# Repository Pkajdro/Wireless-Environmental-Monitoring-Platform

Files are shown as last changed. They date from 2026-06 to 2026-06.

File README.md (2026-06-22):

# Wireless Environmental Monitoring Platform

rn_image_picker_lib_temp_3451f50a-21aa-435d-9f39-d2db277a8afb

<br>

A remotely operated mobile robotics platform engineered for atmospheric data acquisition and exploration. The system enables remote clontrol of the driving platform and acquisition of humidity, pressure and temperature of air. Key feature is modularity - most parts can be changed without changing others and the whole robot, allowing for diffrent configurations.

This robot was made in collaboration with @Pita5488, who programed and installed the sensors, made the final versions of the code and of the KiCad scheme, etc.

<br>

# Key features
 - wireless control
 - modularity
 - built for uneven urban terrain
 - records temperature, pressure and humidity of the air

<br>
<br>

# Architecture
### Software and digital tool and languages:
 - Arduino IDE
 - KiCad
 - C/C++
 - Python
 - VScode
 - Tinkercad

### Hardware
 - Arduino Rev 4 Wifi/BT
 - L298N engine driver
 - 18650 batteries
 - WS2812 led stripe
 - DHT11 temperature and humidity sensor
 - HC-SR04 UV distance sensor
 - BMP280 digital barometer
 - yellow 3-6V DC Motors
 - other electronic

### Construction
- wooden main corpus
- wooden electronics board
- 3D-printed wheel guides

<br>
<br>

# In depth look
### Robots pourpose
Robot's main function is to record meterological data, while being remotely controled. 
The wireless control system allows the user to reach terrains humans can't or should't because of possible danger, like vents, contruction zones, post accidents zones like labs, radioactive terrain, etc.

### About software
We used the Arduino IDE, as it suited our need. We programmed the sensors, engines, etc., in many .h files to make the project clearer.

We decided that the robot should be controlled via laptop, so we created a Python app, allowing us to do so.

### About hardware
Our hardware was mostly mounted on the electronics board on the top of the robot.

### About construction
The whole idea of the robot was 1) to be large, so that it can be used in ubran enviroment, 2) to be modular, so that we can use it for many things.

Robots size is aprox. 50 cm in lenght, 25 in width and 30 in height. We decided to use wood for large parts of the robot, since PETG would be less sturdy, and wouldn't allow us to easily use bolts to mount it.

The main corpus is entirely made out of wpieces of wood bolted togather - the top part of the main corpus and sides used to bolt guides in.

Guides are made out of PETG using a 3D-printer. They have a 45° curve, to further strenghten its abilities to manuver in unever terrain

At the very top sits the electronics board, on which we mounded electronics like Arduino, engine drives, batteries and the breadboard with sensors.

### Modularity: The key aspect of Robot's construction
From the very beggining we decided to have a modelar build of the robot.

What does it mean?

It means that you can change almost every part easily and without changing any other parts.
We used M3 bolts with nuts on guides and the electronics board with, aloowing use to swapp them simply by unscrewing a few bolts.

Each engine guide (or "leg") can be individualy changed, allowing for diffrent configurations - feature which I already use (more about this is "What's next?" senction further down).
The detachable electronics board has also already come in handy - when I needed to code or tinker around it, i just detached it and didn't have to bring the whole robot with me.
It also allows the robot to have multiple pourposes, since all it takes to completly change the electronics is to swap in the new boards, connect engines to the driver, and you are good to go.

<br>
<br>

# What's still to fix?
The main problem with the robot is it size and weight - it causes the rotation of the to be very slow and unreliable.

During our testing we understood that because of robot's size, weight and teh fact that it's a skid-steer robot, it will not rotate well in this configuration.

Which takes us to...

<br>
<br>

# What's next?
--> The 2.0 version

What I aim to acomplish now is to piece by piece change the robot, so that the movement problem will be fixed.
My engineering thesis patreon sugested to use passive wheels on the back, so that you only need to motors to control the robot.
This idea was already implemented by me - unsuprisingly it did 2 things: fix the movement issue and create new problems.
The problem was that 2 engines at which power supply don't have enough torque for the robot to rotate, as well as it showed that the main corpus of the robot is askewed.

Hence the plan is:
 - test the robot with a new power supply
 - change every wooden part to a 3D-printed one or keep it wooden, but cut wood with a laser, instead of by hand
 - if succefull with previous points - include autonomous software.

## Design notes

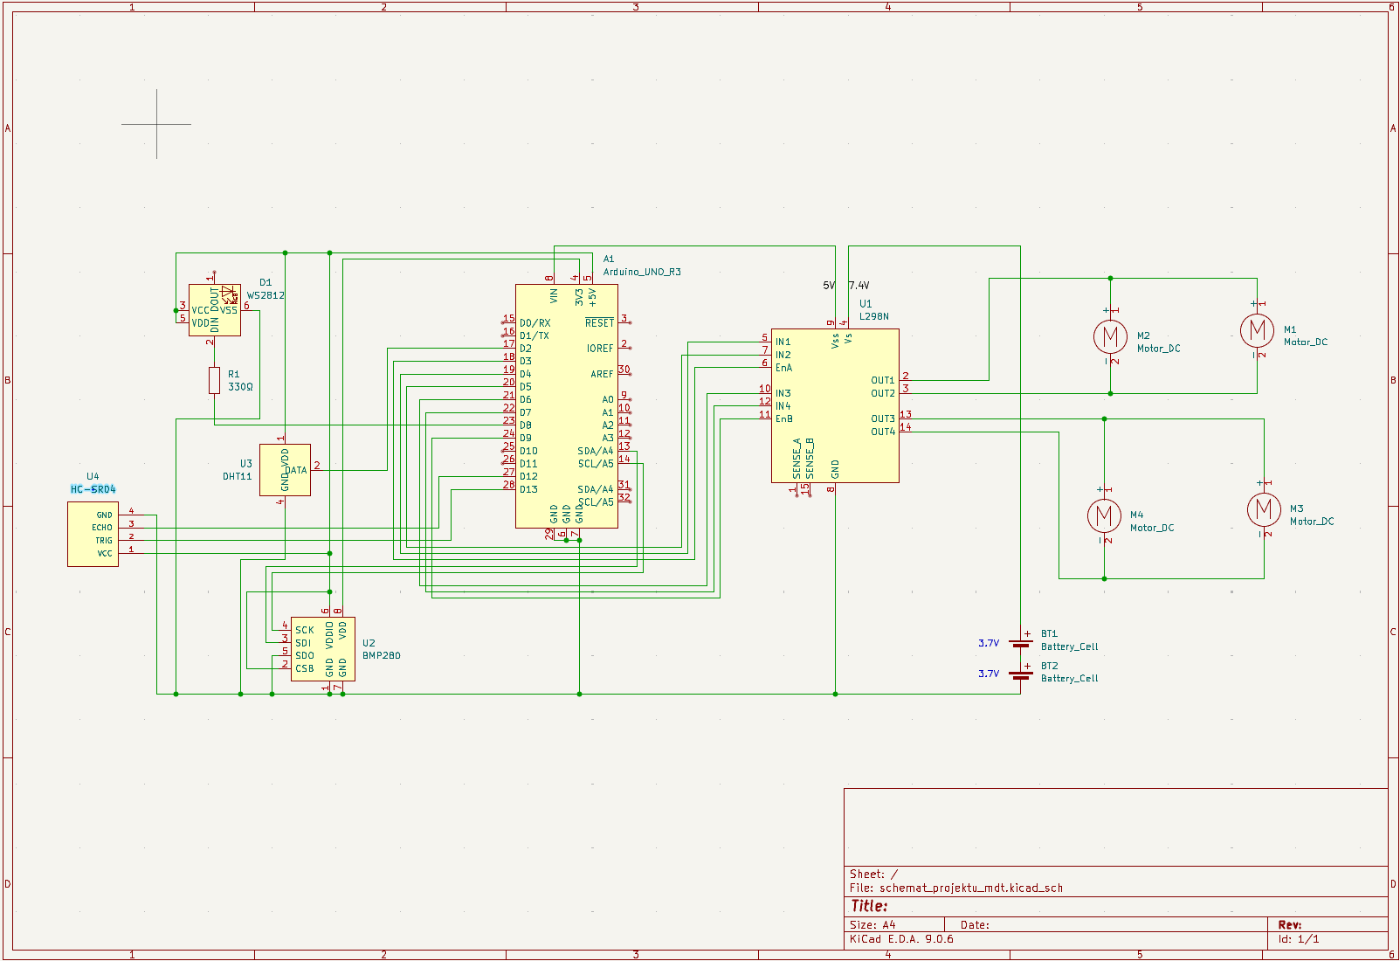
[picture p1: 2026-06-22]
KiCad/KiCad scheme screenshot.png

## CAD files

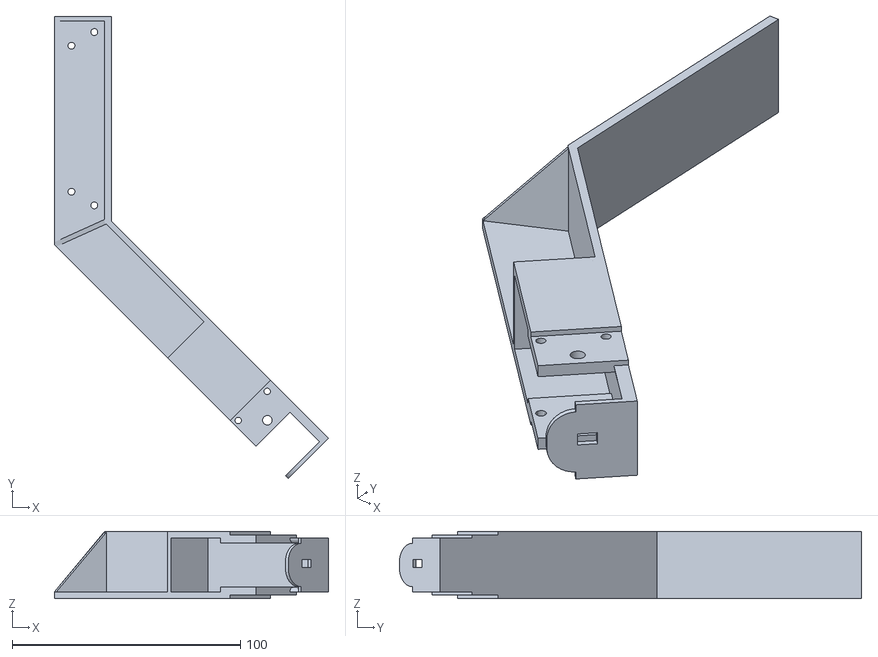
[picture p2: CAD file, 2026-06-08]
RB-pop.stl
120.2 x 202.5 x 29.5

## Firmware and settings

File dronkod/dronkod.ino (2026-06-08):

#include <Adafruit_NeoPixel.h>
#include <Wire.h>
#include "ultrasonic.h"
#include "config.h"
#include "sensor.h"
#include "engine.h"
#include "net.h"
Adafruit_NeoPixel pixels(NUMPIXELS, PIN, NEO_GRB + NEO_KHZ800);

unsigned long lastTrigger = 0;
unsigned long lastSendTime = 0;
const unsigned long triggerInterval = 80;
bool readingSensors = false;
bool manewrCofania = false;           
unsigned long czasStartuCofania = 0; 
const unsigned long czasCofania = 2000; 

void setup() {
    Serial.begin(115200);

    pixels.begin();
    pixels.clear();
    pixels.show();

    pinMode(TRIG, OUTPUT);
    digitalWrite(TRIG, LOW);

    pinMode(ECHO, INPUT);
    attachInterrupt(digitalPinToInterrupt(ECHO), echoISR, CHANGE);
    Wire.begin();
    if (!setup_bmp280()) {
      Serial.println("BMP280 init FAILED");
      //while(1);
    }
    konfigurujSilniki();
    setupSieci();
}

void loop() {
    unsigned long now = millis();
    //silnik
    utrzymujPolaczenie();
  
    if (manewrCofania) {
        if (now - czasStartuCofania >= czasCofania) {
            stopTyl();             
            manewrCofania = false; 
            Serial.println("Koniec manewru cofania.");
        }
    }
    if (!manewrCofania) {
      String komenda = odbierzKomende();
      if (komenda != "") {
        
        if (komenda.equalsIgnoreCase("1")) {
          jedzDoPrzodu();
          Serial.println("Przod");
        } 
        else if (komenda.equalsIgnoreCase("2")) {
          stopPrzod();
          Serial.println("stop");
        } 
        else if (komenda.equalsIgnoreCase("3")) {
          jedzDoTylu();
          Serial.println("tyl");
        } 
        else if (komenda.equalsIgnoreCase("4")) {
          stopTyl();
          Serial.println("stoptyl");
        } 
        else if (komenda.equalsIgnoreCase("5")) {
          skrecWLewo();
          Serial.println("lewo");
        } 
        else if (komenda.equalsIgnoreCase("6")) {
          stopLewo();
          Serial.println("stoplewo");
        } 
        else if (komenda.equalsIgnoreCase("7")) {
          skrecWPrawo();
          Serial.println("prawo");
        } 
        else if (komenda.equalsIgnoreCase("8")) {
          stopPrawo();
          Serial.println("stopprawo");
        }
      }
    }
    //koniec silnik
    
    if (now - lastSendTime >= 5000) {
      lastSendTime = now;
      readingSensors = true;
      float temperature, pressure, humidity;

      read_bmp280(temperature, pressure);
      output_bmp280(temperature, pressure);

      read_dht11(humidity);
      output_dht11(humidity);
      
      //sendMeasurement(temperature, pressure, humidity, "Salon"); //zakomentować jak nie używa się strony
      readingSensors = false;

      
    }
  
    if (!readingSensors && (now - lastTrigger >= triggerInterval)) {
        lastTrigger = now;
        triggerSensor(); // 
    }
    float dystans = getLastDistance();

    // Jeśli wykryto przeszkodę (< 10cm) 
    if (!manewrCofania && dystans > 0.1 && dystans < 10.0) {
        Serial.println("Przeszkoda! Start cofania (NON-BLOCKING)...");
        
        stopWszystko();        
        jedzDoTylu();          
        
        manewrCofania = true;   
        czasStartuCofania = now;
    }
   
    checkEcho();

   
}

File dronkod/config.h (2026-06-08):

#ifndef CONFIG_H
#define CONFIG_H


#define DHT11_PIN 2 //Do ustawienia
#define ENA 3
#define IN1 4
#define IN2 5
#define IN3 6
#define IN4 7
#define ENB 9
#define PIN 8 // NeoPixel
#define NUMPIXELS 8
#define DELAYVAL 500
#define ECHO 12
#define TRIG 13

#endif // CONFIG_H

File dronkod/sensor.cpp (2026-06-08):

#include <Arduino.h>
#include <Adafruit_BMP280.h>
#include <DHT11.h>
#include "sensor.h"
#include "config.h"

Adafruit_BMP280 bmp;
DHT11 dht11(DHT11_PIN);

bool setup_bmp280() {
  if (!bmp.begin(0x76)) {   
    Serial.println("Nie znaleziono czujnika BMP280!");
    return false;
  }
  Serial.println("BMP280 działa poprawnie");
  return true;
}

void output_bmp280(float temperature, float pressure) { 
  Serial.print("Temperatura: ");
  Serial.print(temperature);
  Serial.print(" °C  Cisnienie: ");
  Serial.print(pressure);
  Serial.println(" hPa");
}

void read_bmp280(float &temperature, float &pressure) {
  temperature = bmp.readTemperature();
  pressure = bmp.readPressure() / 100.0; // hPa
}

void output_dht11(float humidity) {  
  Serial.print("Wilgotnosc (%): ");             
  Serial.print(humidity);
} 

void read_dht11(float &humidity) {
  humidity = (float)dht11.readHumidity();
}

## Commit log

2026-06-08 3d printed arm scheme
    [RB-pop.stl]
2026-06-08 KiCad scheme
    [schemat_projektu_mdt.kicad_sch]
